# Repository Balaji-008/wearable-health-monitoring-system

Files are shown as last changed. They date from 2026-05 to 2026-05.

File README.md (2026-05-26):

# ⌚ Wearable Health Monitoring Band / Smartwatch

> A compact, low-power wearable health band built around the Seeed Studio XIAO ESP32S3. Features heart rate & SpO₂ monitoring, hardware-offloaded step tracking, NimBLE wireless data transmission, and an active power-saving state machine.

### 📸 Physical Build & Interface Gallery

| Smartwatch on Wrist (Real Setup) | 3D Printed Heart Rate Sensor Ring |
| :---: | :---: |
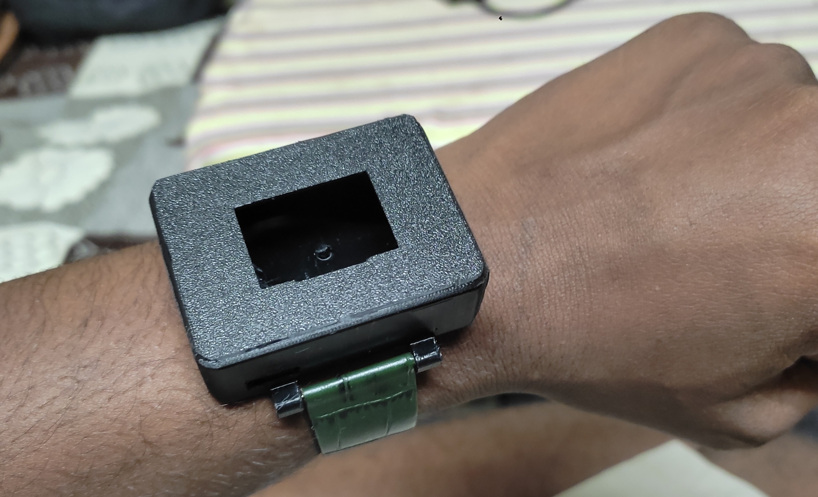
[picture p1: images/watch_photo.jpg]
Smartwatch on Hand
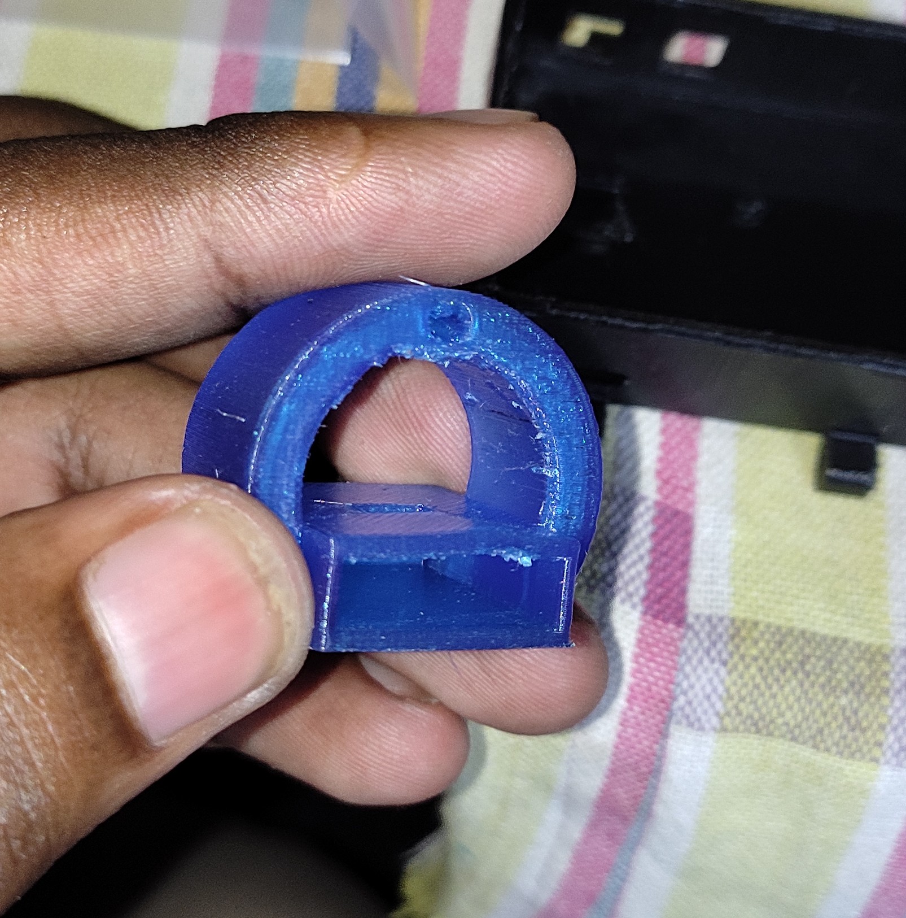
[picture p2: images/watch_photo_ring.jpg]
HR Sensor Ring
|  |  |

---

## ⚡ Key Technical Metrics

| Metric | Value | Details |
|---|---|---|
| **Main Processor** | Seeed Studio XIAO ESP32S3 | Compact, dual-core Tensilica Xtensa LX7 |
| **Biometric Sensor** | MAX30102 | Heart Rate + SpO₂ via I2C |
| **Activity Tracker** | BMA400 | Ultra-low power 3-axis accelerometer |
| **Display** | SSD1306 128×64 | I2C split-color OLED (yellow/blue) |
| **BLE Protocol** | NimBLE-Arduino | Memory-optimized Bluetooth Low Energy |
| **Battery Check** | 12-bit ADC (A0) | Smoothed 47kΩ/100kΩ resistor divider |
| **Power Supply** | 300mAh Li-Po | Compact battery cell integrated in case |
| **Haptic Pin** | 5mm Button Motor | Tactile alert output on GPIO 4 |

---

## 🏗️ Hardware Architecture

```mermaid
graph TD
    Battery["Li-Po Battery cell (300mAh)"] --> ESP32S3["Seeed Studio XIAO ESP32S3"]
    
    subgraph Inputs["Inputs"]
        Button["Push Button (GPIO 3)<br>(Wake / State Controller)"]
        BMA400["BMA400 Accelerometer (I2C)<br>(Hardware Step Interrupt on GPIO 2)"]
        MAX30102["MAX30102 Optical Biometric Sensor (I2C)<br>(Heart Rate + SpO2)"]
    end
    
    subgraph Outputs["Outputs"]
        SSD1306["SSD1306 OLED 128x64 (I2C)<br>(Split-Color Yellow/Blue UI)"]
        Haptic["Vibration Haptic Motor<br>(GPIO 4, PWM alert)"]
    end
    
    Inputs --> ESP32S3
    ESP32S3 --> Outputs
    
    subgraph Firmware["Low-Power Smartwatch OS (ESP32S3 Core)"]
        States["Low-Power State Machine<br>(OFF -> STEPS -> HR -> LONG_ON)"]
        Optical["Optical Finger Detection<br>(100ms Debounce Noise Filter)"]
        Pedometer["Hardware Pedometer Offload<br>(Interrupt Handler)"]
    end
    
    ESP32S3 --> Firmware
    ESP32S3 -->|NimBLE BLE Server| BLE["SensorDevice Telemetry Bridge<br>(String Broadcast every 1s)"]
```

### Complete Pin Configuration

| Peripheral | ESP32S3 Pin | Mode / Description |
|---|---|---|
| **I2C SDA** | **GPIO 5** | Data bus for MAX30102, BMA400, and SSD1306 |
| **I2C SCL** | **GPIO 6** | Clock bus for I2C peripherals |
| **Push Button** | **GPIO 3** | Input with internal pull-up (Wake/State Trigger) |
| **Haptic Motor**| **GPIO 4** | Vibration alert output |
| **BMA400 INT** | **GPIO 2** | Hardware step counter interrupt (Rising edge) |
| **Battery Sense**| **A0 (GPIO 1)**| Analog input for voltage divider check |

---

## 🧠 Core Software Logic & State Machine

### 1. Power State Machine
To maximize wearable battery life, the smartwatch operates in four distinct button-controlled hardware states:

```mermaid
stateDiagram-v2
    [*] --> OFF_STATE : Default
    OFF_STATE --> STEPS_STATE : Short Button Press (OLED wakes, BMA400 active)
    STEPS_STATE --> HR_STATE : Short Button Press (MAX30102 active, reading biometrics)
    HR_STATE --> OFF_STATE : Short Button Press / 60s Auto-Sleep Timeout
    
    OFF_STATE --> LONG_ON_STATE : 2.5s Long Press (Auto-sleep disabled)
    STEPS_STATE --> LONG_ON_STATE : 2.5s Long Press
    HR_STATE --> LONG_ON_STATE : 2.5s Long Press
    
    LONG_ON_STATE --> OFF_STATE : Short Button Press
```

* **`OFF_STATE`:** Display turned OFF (`SSD1306_DISPLAYOFF`), MAX30102 in sleep mode.
* **`STEPS_STATE`:** OLED wakes, showing BMA400 step count and classified activity. MAX30102 remains in standby.
* **`HR_STATE`:** Power-up of the MAX30102 for active heart rate and SpO₂ readings.
* **`LONG_ON_STATE`:** Triggered by a **2.5-second long press** (confirmed by a 250ms haptic buzz). Overrides the auto-sleep, locking the device continuously ON.
* **Auto-Sleep:** If running in standard states (`STEPS_STATE` or `HR_STATE`), the system monitors idle time and shuts down completely after **60 seconds** of inactivity (`AUTO_OFF_MS = 60000`).

### 2. Optical Finger Detection
To prevent false measurements when the watch is off the wrist:
1. The MAX30102 reads raw Infrared (IR) levels.
2. If the IR reading falls below `MIN_IR_THRESHOLD` (**50000**):
   * A debounce timer starts to confirm the finger has been removed.
   * If IR remains low for **100ms** (`NO_FINGER_CONFIRM_MS`), the state machine confirms finger removal (`noFingerConfirmed = true`).
   * The UI displays `"No Finger"`, and the BPM/SpO₂ buffers are safely cleared.

### 3. Hardware-Offloaded Step Counting
Step counting is offloaded entirely to the BMA400's internal hardware ASIC:
* The ESP32S3 configures step counter interrupts on channel 1 (`BMA400_INT_CHANNEL_1`) as active push-pull.
* When motion is detected, the BMA400 fires a rising-edge interrupt to **GPIO 2** of the ESP32S3.
* The ESP32S3 wakes briefly, updates the global `bmaStepCount` and `bmaActivityType` (`Walking`, `Running`, `Standing still`), and returns to standby, leaving the main CPU completely unburdened.

---

## 📁 Repository Structure

📂 **`Final_Watch_code/`** — Core ESP32S3 smartwatch Arduino firmware  
  * `Final_Watch_code.ino` — Core smartwatch OS, NimBLE stack, and power state machine  
📂 **`3D print final/`** — Mechanical 3D printing casing & CAD STL design files:  
  * `HR ring v2.stl` — Custom design for the optical sensor ring spacer  
  * `Watch Cap 1 v1.stl` — Casing top cap protecting the ESP32S3 and OLED assembly  
  * `Watch v1 v5.stl` — Main smartwatch chassis housing the 300mAh battery, button, and wiring  
  * `HR ring v2.png` — Casing CAD diagram render  
📂 **`images/`** — Real-world setup photos and interface details  
  * `watch_photo.jpg` — High-definition physical photo of the smartwatch active on the wrist  
  * `watch_photo_ring.jpg` — High-definition physical photo of the custom 3D printed ring  
  * `watch_face.jpg` — OLED screen showing biometrics and battery status  
  * `app_interface.jpg` — Mobile app showing active BLE health telemetry  
📄 **`Smartwatch_Final_Report.pdf`** — Complete technical project documentation report  
📄 **`README.md`** — Core project documentation  

---

## 🚀 Getting Started

### Prerequisites
- **Arduino IDE** with ESP32 board package
- **Required Libraries:**
  * `NimBLE-Arduino` (Memory-optimized BLE stack)
  * `Adafruit_SSD1306` & `Adafruit_GFX`
  * `SparkFun_BMA400_Arduino_Library`
  * `MAX30105` (Adafruit/SparkFun variant including `spo2_algorithm.h`)

### Flashing Firmware
1. Open `Final_Watch_code/Final_Watch_code.ino` in the Arduino IDE.
2. Select **XIAO ESP32S3** as the target board.
3. Click **Upload** to compile and flash.

---

## 🔬 Lessons Learned & Engineering Pivots

1. **NimBLE Stack Selection:** The standard ESP32 BLE library consumes nearly **1.1MB of flash memory**, leaving almost zero room for user interface graphics and custom sensor logics. Transitioning to **NimBLE** reduced the memory footprint by over **60%**, preserving room for high-fidelity UI rendering and reliable multitasking state machines.
2. **Voltage Divider Impedance:** The internal input impedance of the ESP32S3's analog pins can cause voltage sag under high-value resistor dividers. Tuning to a **47kΩ + 100kΩ divider** provided the ideal balance between minimal battery parasitic drain and accurate 12-bit battery state-of-charge measurements on **A0**.
3. **Optomechanical Isolation:** Switching cell casing from Nylon Carbon Fiber to **PETG** provided superior skin comfort. Added a compliance-fit **TPU inner ring** around the MAX30102 sensor lens. This soft gasket blocks ambient light leakage while keeping the skin-contact force gentle and stable.

---

## 👤 Author

**Balaji Rayudu S**  
B.Tech Electronics & Computers Engineering  
Amrita Vishwa Vidyapeetham, Bengaluru

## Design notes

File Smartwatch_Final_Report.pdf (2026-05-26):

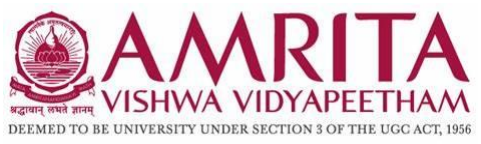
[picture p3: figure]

### AMRITA SCHOOL OF ENGINEERING, BENGALURU

### DEPARTMENT OF ELECTRONICS & COMMUNICATION ENGINEERING

## B. TECH. II SEMESTER(ECE/EAC) AY 2023-2024

## 23ECE184 INTRODUCTION TO INTERNET OF THING

## LAB

## SYSTEM DESIGN REPORT

## MAY 2025

Submitted by

BL.EN.U4EAC24009 | B. AKSHAY SARADHI
BL.EN.U4EAC24010 | B. ADITYA
BL.EN.U4EAC24011 | BALAJI RAYUDU

### BATCH NUMBER: 05

### Faculty Examiner Signature with Date

TITLE: - HEALTH MONITORING SYSTEM

OBJECTIVE: - To create a wearable device using ESP32, MAX30102, display, and BAM400 to continuously monitor and log real-time health data (heart rate and SpO2)

COMPONENTS REQUIRED ALONG WITH THEIR SPECIFICATIONS: -

Sl. No | Name of the Component | Specification | Quantity
1. | ESP 32 | S3 | 1
2. | DISPLAY | OLED | 1
3. | BMA400 | | 1
4. | MAX30102 | | 1
5. | WATCH 3D CASE | 3D PRINTED | 1
6. | BATTERY | LI-PO 300Mah | 1
7. | BUTTON MOTOR | 5mm | 1

MOTIVATION/SOCIATAL/INDUSTRIAL IMPACT: -

This wearable health monitoring device is designed to address the growing demand for continuous, real-time health tracking. By measuring heart rate, SpO₂, and physical activity, it empowers individuals to manage their well-being proactively. It offers significant societal benefits by aiding early detection of health issues, supporting elderly care, and providing health access in remote areas. Industrially, it contributes to the expansion of digital healthcare, remote patient monitoring, and fitness tech, reducing the burden on traditional medical systems while enabling scalable, data-driven healthcare solutions.

BLOCK DIAGRAM/SYSTEM DESIGN: -

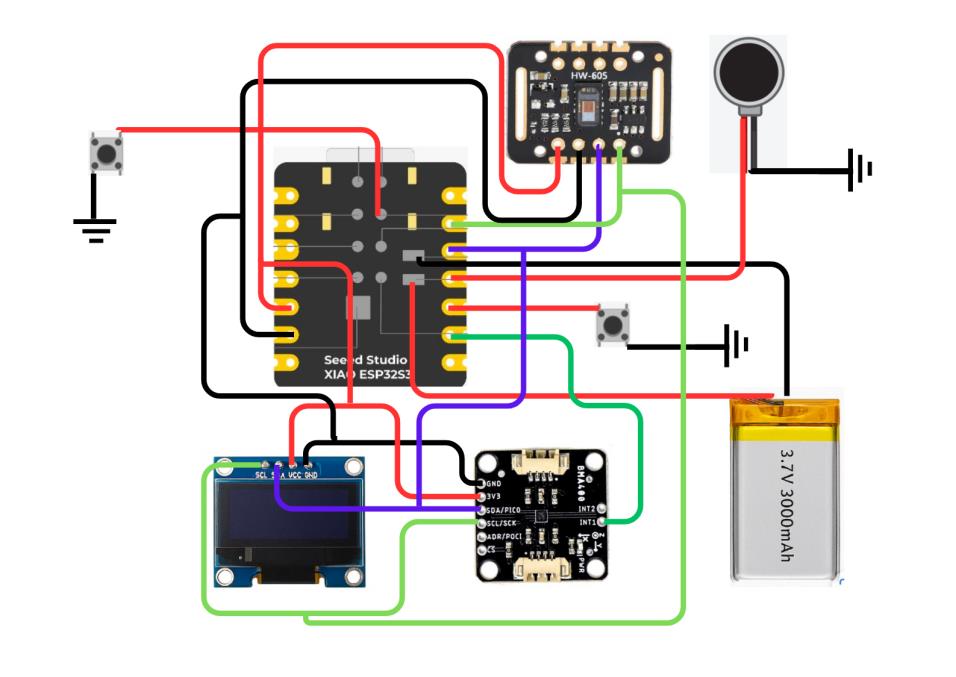
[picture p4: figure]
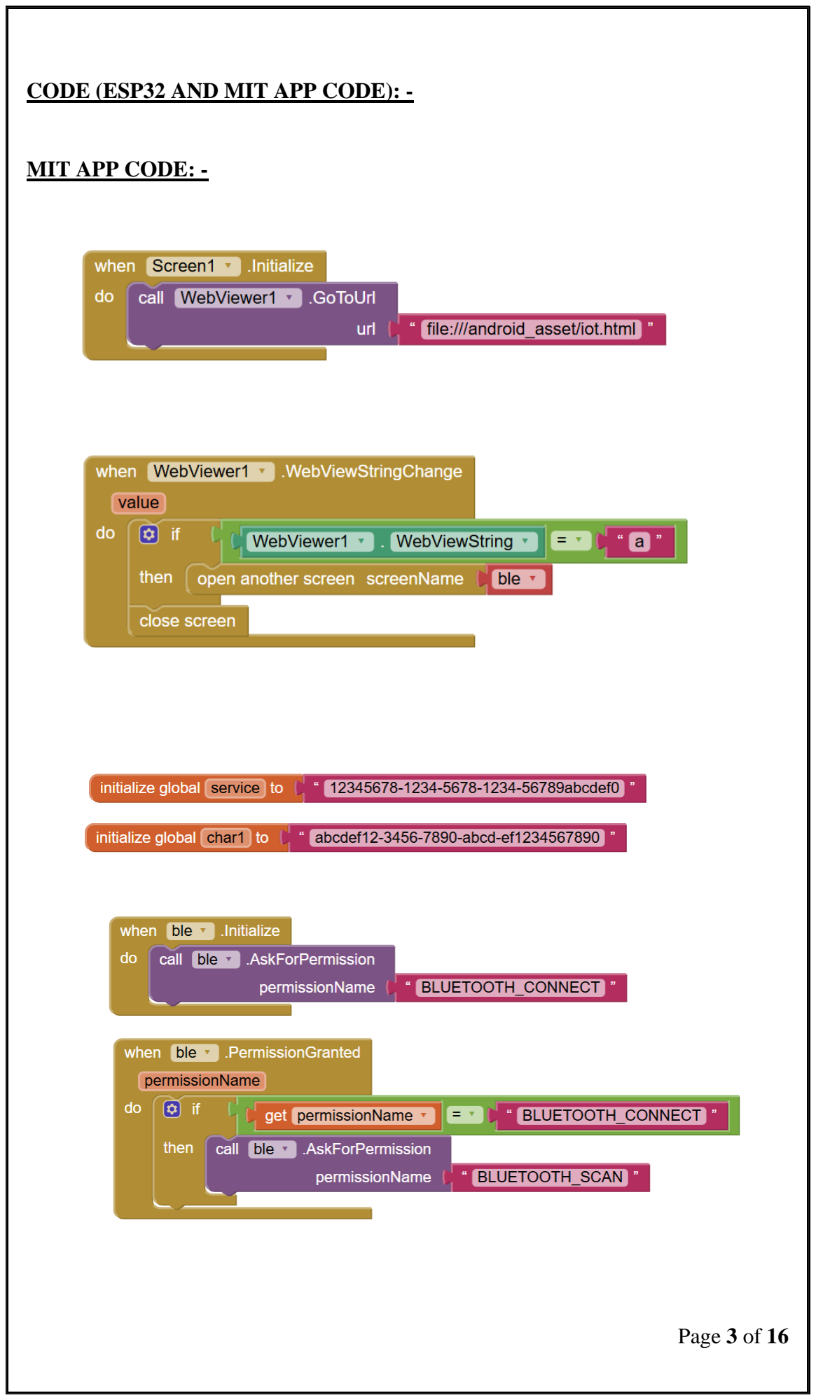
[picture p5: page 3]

CODE (ESP32 AND MIT APP CODE): -

MIT APP CODE: -

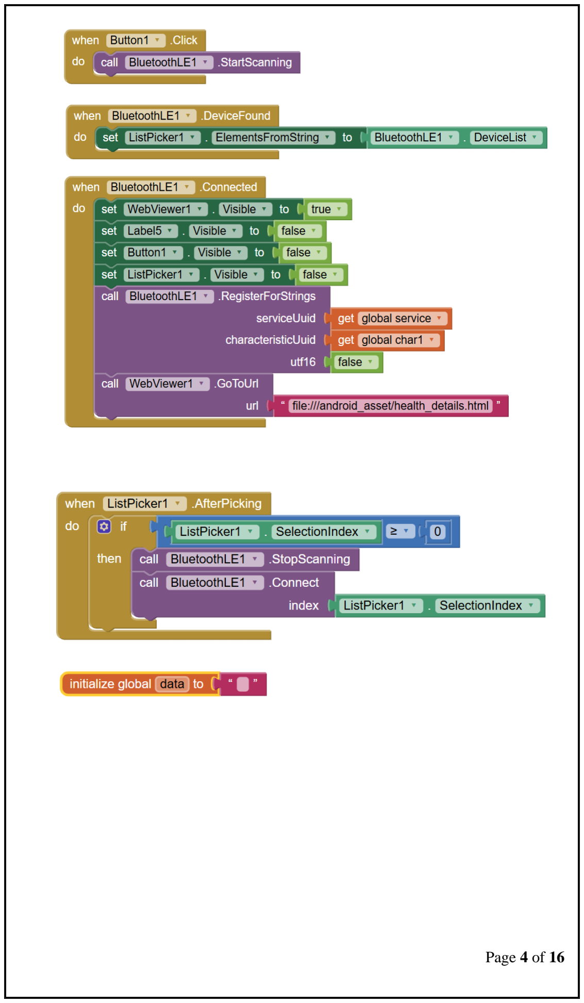
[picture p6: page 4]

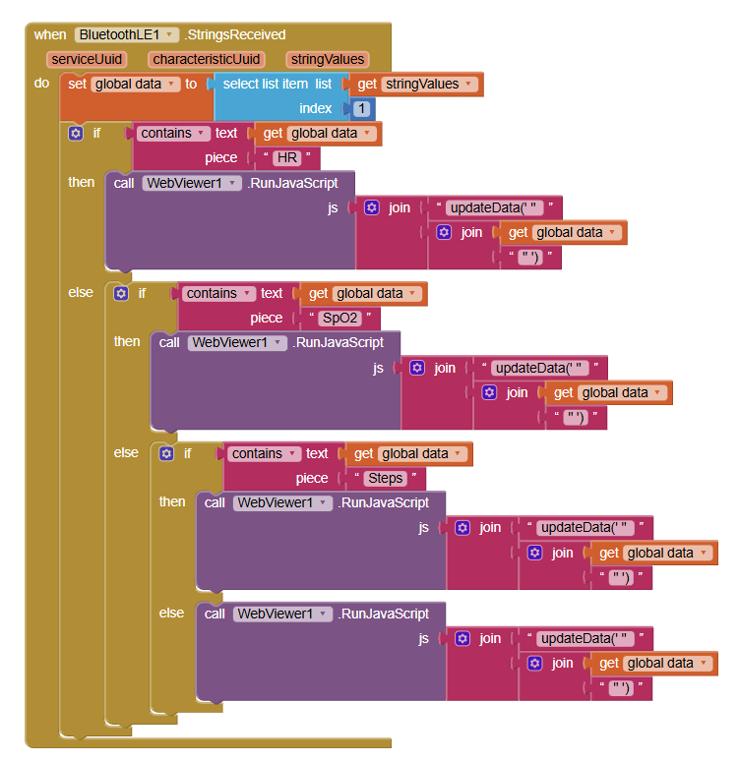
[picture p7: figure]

ESP 32 CODE:-

#include <Arduino.h>

#include <Wire.h>

#include "SparkFun_BMA400_Arduino_Library.h" #include "MAX30105.h"

#include "spo2_algorithm.h"

#include <Adafruit_GFX.h>

#include <Adafruit_SSD1306.h> #include <NimBLEDevice.h>

#define SCREEN_WIDTH 128

#define SCREEN_HEIGHT 64

#define OLED_RESET -1

#define BUTTON_PIN 3

#define HAPTIC_PIN 4

#define DEBOUNCE_DELAY 50

#define LONG_PRESS_THRESHOLD 2500 #define AUTO_OFF_MS 60000

#define MIN_IR_THRESHOLD 50000 #define NO_FINGER_CONFIRM_MS 100

#define BATTERY_PIN A0

#define R_TOP 47000.0

#define R_BOTTOM 100000.0

#define V_REF 3.3

#define ADC_MAX 4095.0

#define SENSOR_SERVICE_UUID | "12345678-1234-5678-1234-56789abcdef0"

#define SENSOR_CHAR_UUID | "abcdef12-3456-7890-abcd-ef1234567890"

Adafruit_SSD1306 display(SCREEN_WIDTH, SCREEN_HEIGHT, &Wire, OLED_RESET);
BMA400 accelerometer;
uint8_t i2cAddress = BMA400_I2C_ADDRESS_DEFAULT;
const int interruptPin = 2;
volatile bool interruptOccurred = false;
uint32_t bmaStepCount = 0;
uint8_t bmaActivityType = 0;

MAX30105 particleSensor;
bool maxPresent = true;
const byte LED_BRIGHTNESS = 0x1F; const int SAMPLE_RATE = 300; const int DATA_BUFFER_SIZE = 100; const int PULSE_WIDTH = 411;
const int ADC_RANGE = 4096;
uint32_t irBuffer[DATA_BUFFER_SIZE]; uint32_t redBuffer[DATA_BUFFER_SIZE]; int bufferIndex = 0;
int32_t spo2;
int8_t validSPO2;
float bpm = 0;
unsigned long lastBeatTime = 0;
const int HR_FILTER_SIZE = 10;
float beatIntervals[HR_FILTER_SIZE] = {0}; int beatIntervalIndex = 0;

enum DeviceState {
OFF_STATE,
STEPS_STATE,
HR_STATE,

LONG_ON_STATE
};
DeviceState deviceState = OFF_STATE; bool longPressActive = false;
bool buttonCurrentlyPressed = false; unsigned long buttonPressTime = 0; unsigned long lastActivityTime = 0; static bool prevButtonState = HIGH; static unsigned long lastChangeTime = 0;

static unsigned long noFingerStartTime = 0; static bool noFingerConfirmed = false;

NimBLEServer* pBLEServer = nullptr; NimBLEService* pBLEService = nullptr; NimBLECharacteristic* pSensorCharacteristic = nullptr;

void setupBLE() {
NimBLEDevice::init("SensorDevice");
pBLEServer = NimBLEDevice::createServer();
pBLEService = pBLEServer->createService(SENSOR_SERVICE_UUID); pSensorCharacteristic = pBLEService->createCharacteristic( SENSOR_CHAR_UUID,
NIMBLE_PROPERTY::READ | NIMBLE_PROPERTY::NOTIFY
);
pSensorCharacteristic->setValue("No Data");
pBLEService->start();
NimBLEAdvertising* pAdvertising = NimBLEDevice::getAdvertising(); pAdvertising->setName("SensorDevice"); pAdvertising->addServiceUUID(SENSOR_SERVICE_UUID); pAdvertising->start();
}

void updateBLE() {
if (!pBLEServer || pBLEServer->getConnectedCount() == 0) return;

static uint8_t bleState = 0;
static unsigned long lastBLETime = 0;
const unsigned long gapTime = 1000;

if (millis() - lastBLETime < gapTime) return; lastBLETime = millis();

String dataToSend;
switch (bleState) {
case 0: dataToSend = "HR:" + String(bpm, 1); break;
case 1: dataToSend = "SpO2:" + String(spo2); break;
case 2: dataToSend = "Steps:" + String(bmaStepCount); break; case 3: {
String activity;

switch (bmaActivityType) {
case BMA400_RUN_ACT: activity = "Running"; break; case BMA400_WALK_ACT: activity = "Walking"; break; case BMA400_STILL_ACT: activity = "Standing"; break; default: activity = "Unknown"; break;
}
dataToSend = "Activity:" + activity;
break;
}
}

pSensorCharacteristic->setValue(dataToSend.c_str()); pSensorCharacteristic->notify();
bleState = (bleState + 1) % 4;
}

void setupHaptic() {
pinMode(HAPTIC_PIN, OUTPUT); digitalWrite(HAPTIC_PIN, LOW);
}

void buzzHaptic(unsigned long durationMs) { digitalWrite(HAPTIC_PIN, HIGH); delay(durationMs);
digitalWrite(HAPTIC_PIN, LOW);
}

int getBatteryPercentage() {
static int lastPct = -1;
float raw = analogRead(BATTERY_PIN);
float v_adc = (raw / ADC_MAX) * V_REF;
float v_bat = v_adc * (R_TOP + R_BOTTOM) / R_BOTTOM; v_bat = constrain(v_bat, 3.0, 4.2);
int pct = map(v_bat * 100, 300, 420, 0, 100);
if (lastPct < 0 || abs(pct - lastPct) >= 3) lastPct = pct;
return lastPct;
}

void drawBatteryIcon() {
int pct = getBatteryPercentage(); int x = SCREEN_WIDTH - 28; int y = 0;
int w = 20;
int h = 8;
int level = map(pct, 0, 100, 0, w - 4);

display.drawRect(x, y, w, h, SSD1306_WHITE); display.drawRect(x + w, y + 2, 2, 4, SSD1306_WHITE); display.fillRect(x + 2, y + 2, level, h - 4, SSD1306_WHITE);

display.setTextSize(1);
display.setTextColor(SSD1306_WHITE); display.setCursor(x - 18, y); display.print(pct);
display.print("%");
}

void setup() {
Serial.begin(115200);
Wire.begin(5, 6);
pinMode(BUTTON_PIN, INPUT_PULLUP); setupHaptic();

if (!display.begin(SSD1306_SWITCHCAPVCC, 0x3C)) { while (1);
}
display.clearDisplay();
display.setTextSize(1);
display.setTextColor(SSD1306_WHITE); display.setCursor(0, 0);
display.println("Combined Sensor Init"); display.display();
delay(1000);

while (accelerometer.beginI2C(i2cAddress) != BMA400_OK) { display.clearDisplay();
display.setCursor(0, 0);
display.println("BMA400 not connected!"); display.display();
delay(1000);
}

bma400_step_int_conf config = { .int_chan = BMA400_INT_CHANNEL_1 }; accelerometer.setStepCounterInterrupt(&config); accelerometer.setInterruptPinMode(BMA400_INT_CHANNEL_1, BMA400_INT_PUSH_PULL_ACTIVE_1); accelerometer.enableInterrupt(BMA400_STEP_COUNTER_INT_EN, true); attachInterrupt(digitalPinToInterrupt(interruptPin), bma400InterruptHandler, RISING);

if (!particleSensor.begin(Wire, I2C_SPEED_FAST)) {
maxPresent = false;
display.clearDisplay();
display.setCursor(0, 0);
display.println("MAX30105 not"); display.println("connected!"); display.display();
delay(2000);
} else {

particleSensor.setup(LED_BRIGHTNESS, 4, 2, SAMPLE_RATE, PULSE_WIDTH, ADC_RANGE);
particleSensor.enableDIETEMPRDY();
delay(3000);
}

setupBLE();
}

void loop() {
handleButtonPress();

if (!longPressActive && (deviceState == STEPS_STATE || deviceState == HR_STATE)) {
if (millis() - lastActivityTime >= AUTO_OFF_MS) deviceState = OFF_STATE; }

if (deviceState == OFF_STATE) { display.ssd1306_command(SSD1306_DISPLAYOFF); return;
} else {
display.ssd1306_command(SSD1306_DISPLAYON); }

if (interruptOccurred) {
interruptOccurred = false;
uint16_t interruptStatus = 0; accelerometer.getInterruptStatus(&interruptStatus);
if (interruptStatus & BMA400_ASSERTED_STEP_INT) { accelerometer.getStepCount(&bmaStepCount, &bmaActivityType); }
}

if (maxPresent && (deviceState == HR_STATE || deviceState == LONG_ON_STATE)) {
static unsigned long lastSample = millis();
if (millis() - lastSample >= 10) {
lastSample = millis();
float irValue = particleSensor.getIR(); float redValue = particleSensor.getRed(); irBuffer[bufferIndex] = irValue; redBuffer[bufferIndex] = redValue; detectHeartBeat(irValue);
bufferIndex++;
if (bufferIndex >= DATA_BUFFER_SIZE) { processSpO2();
bufferIndex = 0;
}
}
}

updateDisplay();
updateBLE();
}

void handleButtonPress() {
bool rawState = digitalRead(BUTTON_PIN);
if (rawState != prevButtonState) lastChangeTime = millis();
bool stableState = (millis() - lastChangeTime < DEBOUNCE_DELAY) ? prevButtonState : rawState;
prevButtonState = rawState;

if (!buttonCurrentlyPressed && stableState == LOW) { buttonPressTime = millis();
buttonCurrentlyPressed = true;
}

if (buttonCurrentlyPressed && stableState == LOW && !longPressActive && millis() - buttonPressTime >= LONG_PRESS_THRESHOLD) { longPressActive = true;
buzzHaptic(250);
deviceState = LONG_ON_STATE;
lastActivityTime = millis();
}

if (buttonCurrentlyPressed && stableState == HIGH) {
if (millis() - buttonPressTime < LONG_PRESS_THRESHOLD) { buzzHaptic(150);
if (deviceState == OFF_STATE) deviceState = STEPS_STATE; else if (deviceState == STEPS_STATE) deviceState = HR_STATE; else if (deviceState == HR_STATE) deviceState = OFF_STATE; else if (deviceState == LONG_ON_STATE) {
deviceState = OFF_STATE;
longPressActive = false;
}
lastActivityTime = millis(); }
buttonCurrentlyPressed = false; }
}

void detectHeartBeat(float irValue) {
if (irValue < MIN_IR_THRESHOLD) return; static float threshold = 0;
static bool pulseDetected = false;
static float irHistory[DATA_BUFFER_SIZE] = {0}; static int historyIndex = 0;

irHistory[historyIndex] = irValue;
historyIndex = (historyIndex + 1) % DATA_BUFFER_SIZE;

float mean = 0, sumSq = 0;
for (int i = 0; i < DATA_BUFFER_SIZE; i++) mean += irHistory[i];
mean /= DATA_BUFFER_SIZE;
for (int i = 0; i < DATA_BUFFER_SIZE; i++) sumSq += pow(irHistory[i] - mean, 2);
threshold = mean + sqrt(sumSq / DATA_BUFFER_SIZE);

if (!pulseDetected && irValue > threshold) { pulseDetected = true;
unsigned long currentTime = millis();
unsigned long beatDuration = currentTime - lastBeatTime;
if (beatDuration > 300 && beatDuration < 2000) { beatIntervals[beatIntervalIndex] = 60000.0 / beatDuration; beatIntervalIndex = (beatIntervalIndex + 1) % HR_FILTER_SIZE; float total = 0; int count = 0;
for (int i = 0; i < HR_FILTER_SIZE; i++) {
if (beatIntervals[i] > 40 && beatIntervals[i] < 180) {
total += beatIntervals[i]; count++;
}
}
bpm = (count > 0) ? (total / count) : 0; }
lastBeatTime = currentTime;
}
if (pulseDetected && irValue < threshold) pulseDetected = false; }

void processSpO2() {
if (irBuffer[0] < MIN_IR_THRESHOLD) return; int32_t heartRate; int8_t validHeartRate; maxim_heart_rate_and_oxygen_saturation( irBuffer, DATA_BUFFER_SIZE, redBuffer, &spo2, &validSPO2, &heartRate, &validHeartRate );
}

void updateDisplay() {
display.clearDisplay();

if (!maxPresent) {
display.setCursor(0, 0);
display.print("HR sensor X");
}

uint32_t currentIR = (bufferIndex > 0) ? irBuffer[bufferIndex - 1] : 0; display.setCursor(0, 8);
if (currentIR < MIN_IR_THRESHOLD) {
if (noFingerStartTime == 0) {
noFingerStartTime = millis();

noFingerConfirmed = false;
} else if (millis() - noFingerStartTime >= NO_FINGER_CONFIRM_MS) { noFingerConfirmed = true;
}
} else {
noFingerStartTime = 0;
noFingerConfirmed = false; }

if (noFingerConfirmed) {
display.print("No finger");
} else {
display.print("SpO2: ");
if (validSPO2) display.print(spo2); else display.print("---"); display.print("%");
display.setCursor(0, 16);
display.print("BPM: ");
if (bpm > 40 && bpm < 180) display.print(bpm); else display.print("---");
}

display.setCursor(0, 32);
display.print("Steps: ");
display.print(bmaStepCount);

display.setCursor(0, 42);
display.print("Activity: ");
switch (bmaActivityType) {
case BMA400_RUN_ACT: display.print("Running"); break; case BMA400_WALK_ACT: display.print("Walking"); break; case BMA400_STILL_ACT: display.print("Standing"); break; default: display.print("Unknown"); break;
}

drawBatteryIcon();
display.display();
}

SCREENSHOT OF ALL THE WORKING CIRCUITS WITH OUTPUT: -

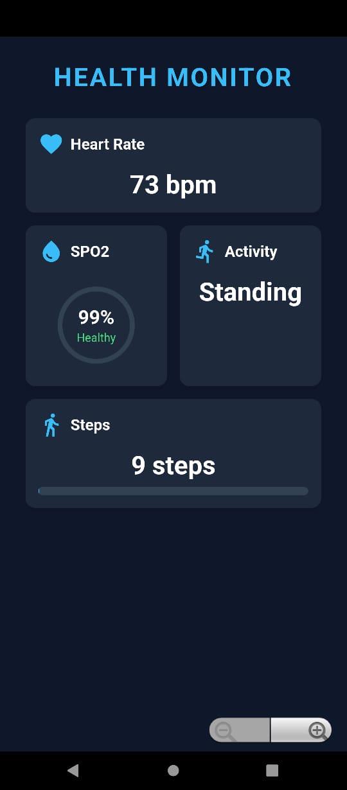
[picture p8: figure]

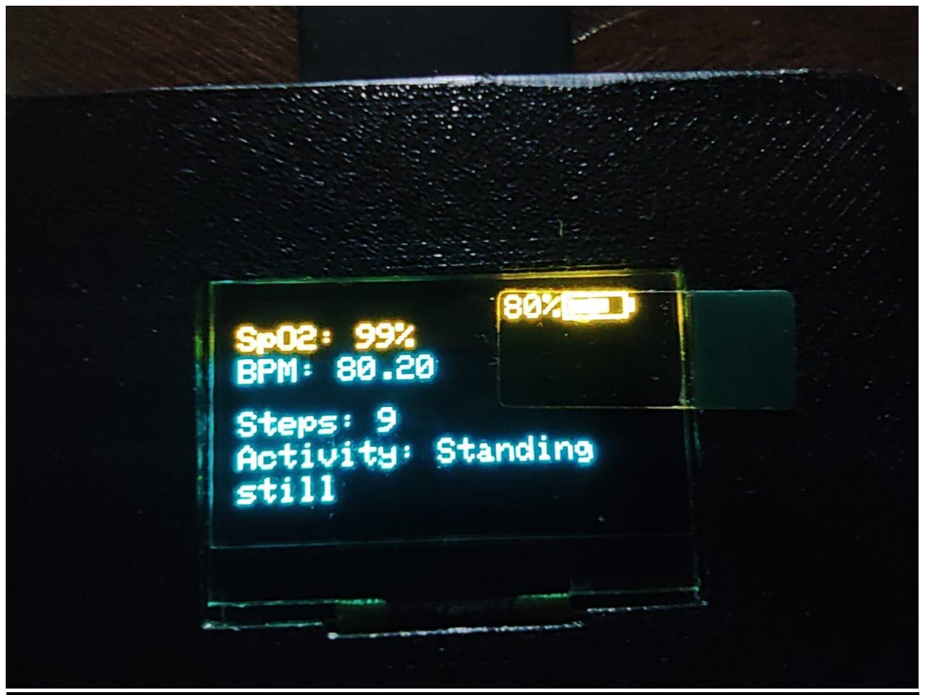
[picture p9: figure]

OBSERVATION TABLE: -

Heart Rate (BPM) | SpO₂ (%) | Steps | Activity | Battery (%) | Finger Detected | BLE Status
76 | 98 | 152 | Walking | 85% | Yes | Connected
80 | 97 | 160 | Walking | 84% | Yes | Connected
82 | 96 | 165 | Running | 83% | Yes | Connected
--- | --- | 165 | Standing | 82% | No | Connected
78 | 98 | 170 | Walking | 82% | Yes | Connected
76 | 99 | 178 | Walking | 81% | Yes | Connected
72 | 98 | 180 | Standing | 80% | Yes | Connected
--- | --- | 180 | Standing | 79% | No | Disconnected

RESULT ANALYSIS: -

The wearable health monitor accurately tracked vital signs and physical activity:

- Heart Rate & SpO₂: The MAX30102 reliably measured heart rate (72–82 BPM) and SpO₂ (96%–99%). "No Finger" detection worked well to prevent false readings.
- Step Counting & Activity: The BMA400 correctly recorded steps and classified activities like walking, running, and standing.
- OLED & Haptic Feedback: Clear real-time display with battery status. Haptic motor provided responsive user feedback.
- BLE Transmission: Sensor data was successfully broadcast via BLE in multiple states and received reliably by connected devices.
- Power Management: Battery voltage was monitored and displayed effectively; auto-off feature conserved energy.

CONCLUSION: -

The developed wearable device successfully integrates the ESP32, MAX30102, BMA400, and OLED display to continuously monitor heart rate, SpO₂, and physical activity. Real-time data logging and BLE transmission enable remote health tracking, offering a practical, cost-effective solution for personal and clinical use. The project demonstrates how embedded systems and IoT can be combined to improve health awareness, support early diagnosis, and promote preventive care through accessible technology.

FUTURE SCOPE: -

This wearable system can be further enhanced by:

- Cloud Integration: Enabling remote data storage and visualization through platforms like Firebase or AWS.
- Additional Sensors: Adding temperature, ECG, or blood pressure sensors for comprehensive health monitoring.
- Machine Learning: Implementing anomaly detection or health prediction algorithms.
- Power Optimization: Improving battery life with energy-efficient components and sleep modes.
- GPS Integration: Adding location-based tracking for outdoor fitness or emergency alerts.

These advancements would make the device more robust, user-friendly, and suitable for both consumer and medical-grade applications.

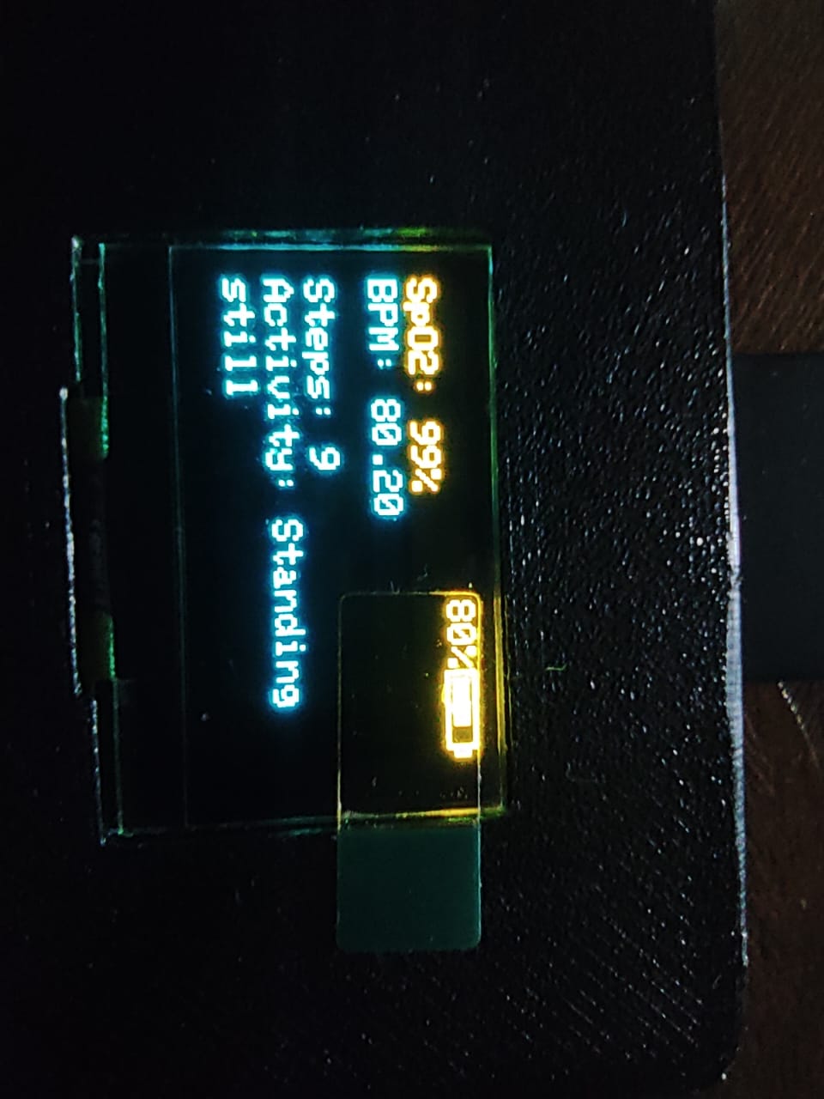
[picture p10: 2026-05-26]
images/watch_face.jpg

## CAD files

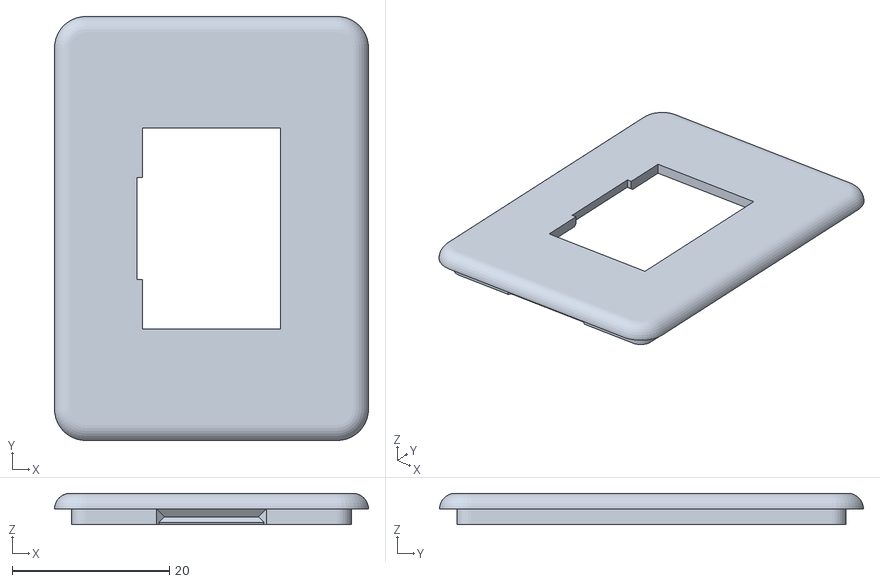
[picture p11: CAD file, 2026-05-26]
3D print final/Watch Cap 1 v1.stl
40.0 x 54.0 x 4.00

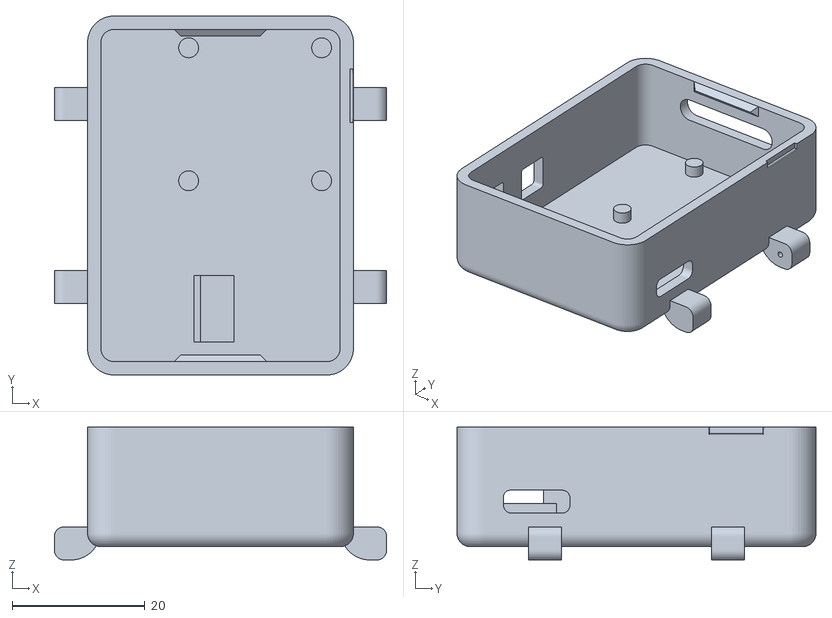
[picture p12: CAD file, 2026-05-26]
3D print final/Watch v1 v5.stl
50.0 x 54.0 x 20.0

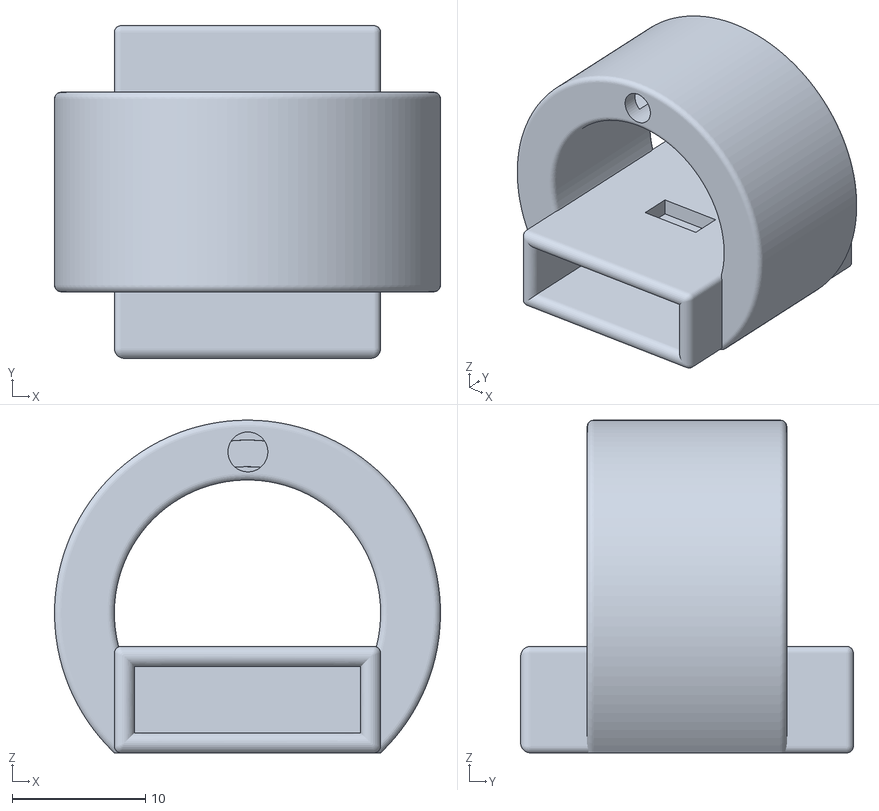
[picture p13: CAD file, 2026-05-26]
3D print final/HR ring v2.stl
29.0 x 25.0 x 25.0

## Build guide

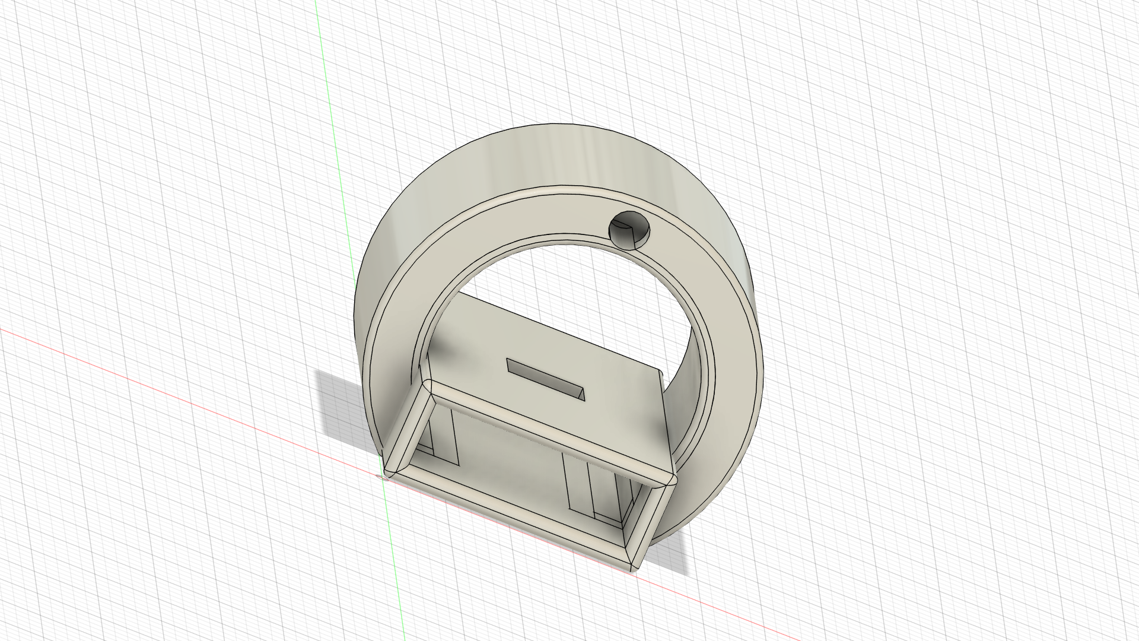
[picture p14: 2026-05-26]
3D print final/HR ring v2.png

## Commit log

2026-05-26 initial commit: add wearable health smartwatch firmware, 3D casing CAD models, visuals, main report, and documentation
    [HR ring v2.stl, Watch Cap 1 v1.stl, Watch v1 v5.stl]
2026-05-26 update: streamline image gallery, document 3D print STL casing/ring components, and polish readme firmware descriptions
